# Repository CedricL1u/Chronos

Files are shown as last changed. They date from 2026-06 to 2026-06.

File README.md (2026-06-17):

# **Chronos \- A Mechanical Pomodoro Timer and Clock**

Final clock render

[Onshape CAD Link](https://cad.onshape.com/documents/4e46eab36ada7087591254e1/w/535417db20a99f0700b6b619/e/2bade0778d34ed4b7359ccd4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)

Zine

# **Overview**

Chronos is a 7-Segment mechanical display that is supposed to function as a pomodoro timer,  clock, or as a regular timer. It’s equipped with speakers that play an alarm noise when time is up and also random sound effects throughout the timer. The speakers let the user know how many pomodoro cycles they have completed after each cycle. They also help Chronos function as an alarm clock when it is put into clock mode. On the top there are two buttons and a rotary encoder which serve as inputs to control it. Chronos is powered by a ESP32-C3 on a custom PCB that drives all the electronics. This device is named Chronos because in Greek it means the quantitative measurement of time that ticks away on a clock.

# **Why does this exist?**

Chronos was mainly built to function as a pomodoro timer, but since it has four numerical displays I decided to make it usable as a clock and regular timer as well. In case you don’t know what a Pomodoro timer is, it’s a simple timer that is used with the Pomodoro Technique. The Pomodoro Technique is a study strategy where you work in short focused intervals (usually 25 minutes) followed by brief breaks (about 5 minutes). You repeat this cycle four times and then you take a longer 15-30 minute break. It’s meant to help you stay focused, reduce procrastination, and make long tasks feel more manageable by splitting them into these repeating cycles. As a student myself who struggled with procrastination and locking in during study sessions I found the pomodoro technique to be extremely useful. I mainly used online timers I found but I found them to be kind of boring so I came up with this device. It’s extremely satisfying because it makes a click every time a digit changes and it’s also cool to see as I study. It’s kind of like an ASMR sound effect while I work or study.

# **Mechanics**

The clock works through four display modules each with seven segments. Each of these 7 segments are connected to a rack and pinion which drives each segment and controls when each segment is displayed and not displayed.  

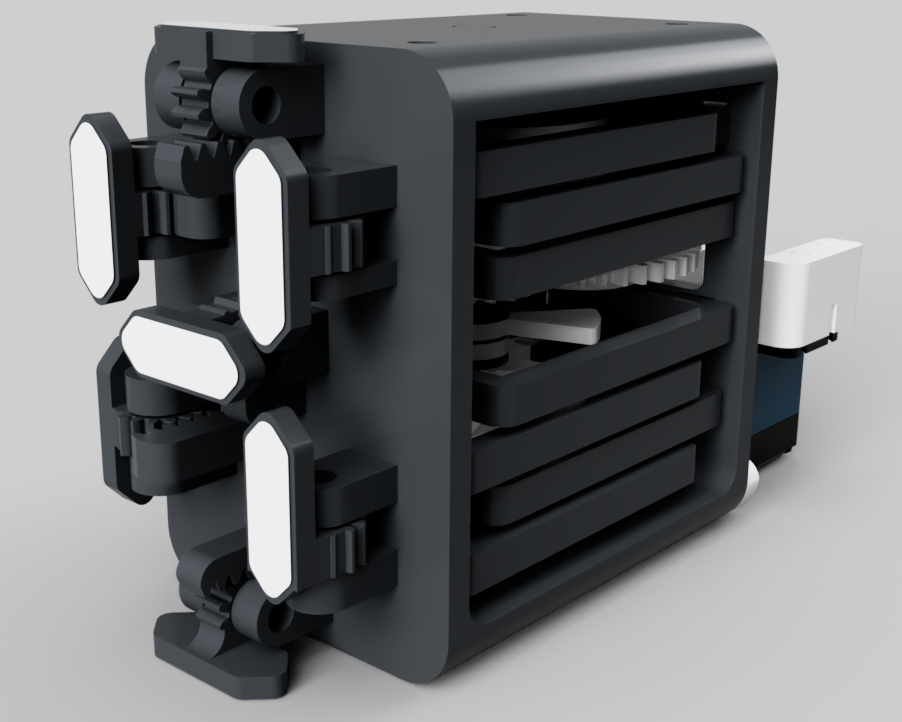
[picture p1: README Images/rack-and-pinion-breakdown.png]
Rack & Pinion Breakdown
  

Each of these racks are driven by a cam and follower mechanism that pushes each rack individually. There is a stack of 14 cams and each follower has 2 cams. One to retract it and one to extend it. Depending on the angle of the shaft different cams are extended and different cams are retracted which control the number displayed. Numbers are displayed at a 36 degree increment of the shaft. For example at 0 degrees the number 0 is displayed and at 72 degrees the number 2 is displayed.



  

The shaft is driven by a servo that is geared to it. 



# **Electronics**

This device is powered by a custom PCB I made in KiCAD that utilizes a Seed Studio XIAO ESP32-C3. On my board I have 4 servo pins which are driven by PWM signals from my microcontroller and the 5V power. There are also two MAX98357A Audio Drive ICs used to control the speakers on my device. I also have a 8-bit IO Expander IC because there weren’t enough GPIO pins on my microcontroller. The 8-Bit IO Expander communicates with my microcontroller through I2C and controls my rotary encoder switch and my two linear switches. The PCB is powered by a 8A 5V AC-DC unit that I plug into the wall and connect into my barrel jack connector. From there the power goes into a reverse polarity mosfet circuit that blocks current if the power supply is connected backwards. This P channel mosfet is then connected to my bulk 2200uF bulk capacitor that acts like a power reservoir to prevent brownouts in case the servos suddenly stall.  





# **Control**

There are 3 methods of input into the clock. A rotary encoder switch, and two cherry mx style linear mechanical keyboard switches. When you rotate the white knob in the middle you can change the duration of the timer when you are in the pomodoro or timer mode. When you click it you can pause or resume the clock. The right button lets you switch between clock mode, pomodoro mode, and timer mode. The left button lets you skip between pomodoro cycles.  


EC11EA5 Rotary Encoder Switch  


Cherry MX Style Linear Mechanical Keyboard Switch 

# **Bill of Materials**

[BOM File](https://github.com/CedricL1u/Chronos/blob/main/BOM.csv)

# **Assembly Instructions**

After you've printed all you're parts you want to first start by putting all of your fikkiwers into the front part of the casing. After you've done that you should align all of your cams on your shaft and place them all into their with your spacers. Once you've done that you need to put the cams into the followers. This can be a bit tricky, a tip I found useful was to wiggle the cams and move the followers when the cams get stuck. This can take a while but after you've done that you need to put the top plate on and screw it in, this will lock the shaft in place. After that mount the servo holder onto the back case plate and screw the servo onto the servo holder. Then screw in the servo gear and attach the back case plate into the rest of the case and align the followers such that they fit inside the hole. Repeat this 3 more times and you should have all 4 display modules. Once you have your display modules, you should first wire everything up. Wire all the jumper cables and servo wires from the pcb to their respective components. Then screw in the PCB and mount all 4 display modules, the 2 speakers, and then screw in the back plate for the case and you should be all good to go.

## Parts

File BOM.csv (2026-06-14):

Product Name | Product Description | Product Link | Unit Price | Qty | Line Total | Running Total
PJ-063BH Power Barrel Jack | Barrel Jack Connector | https://www.digikey.com/en/products/detail/same-sky-formerly-cui-devices/PJ-063BH/2161209 | $1.63000 | 1 | $1.63 | $1.63
MAX98357A | Audio Driver IC | https://www.digikey.com/en/products/detail/analog-devices-inc-maxim-integrated/MAX98357AETE-T/4936122 | $3.73000 | 2 | $7.46 | $9.09
AS03104MR-F-WP-R | Speaker | https://www.digikey.com/en/products/detail/pui-audio-inc/AS03104MR-F-WP-R/17488219 | $9.20000 | 2 | $18.40 | $27.49
Schottky Diode | Schottky Diode | https://www.digikey.com/en/products/detail/mcc-micro-commercial-components/SM5819PL-TP/1793253 | $0.21000 | 1 | $0.21 | $27.70
PCF8574ADWR I2C I/O Expander | IO Expander | https://www.digikey.com/en/products/detail/texas-instruments/PCF8574ADWR/574749 | $1.59000 | 1 | $1.59 | $29.29
10µF 25V Ceramic Cap |  | https://www.digikey.com/en/products/detail/murata-electronics/GRM188R61E106KA73D/9867922 | $0.26000 | 4 | $1.04 | $30.33
0.1µF 25V Ceramic Cap |  | https://www.digikey.com/en/products/detail/kemet/C0603C104K3RACTU/416044 | $0.10000 | 4 | $0.40 | $30.73
10nF 50V Ceramic Cap |  | https://www.digikey.com/en/products/detail/kemet/C0603C103K5RACTU/3838393 | $0.10000 | 4 | $0.40 | $31.13
2200µF 16V Electrolytic Cap | Panasonic / EEU-FR1C222 | https://www.digikey.com/en/products/detail/panasonic-electronic-components/EEU-FR1C222/2433536 | $1.67000 | 1 | $1.67 | $32.80
3-Pin Servo Header |  | https://www.digikey.com/en/products/detail/w%C3%BCrth-elektronik/61300311121/4846825 | $0.13000 | 4 | $0.52 | $33.32
13-Pin Header |  | https://www.digikey.com/en/products/detail/w%C3%BCrth-elektronik/61301311121/4846847 | $0.75000 | 1 | $0.75 | $34.07
AOD403 P-Channel MOSFET | For reverse polarity circuit | https://www.digikey.com/en/products/detail/alpha-omega-semiconductor-inc/AOD403/1855873 | $2.05000 | 1 | $2.05 | $36.12
10kΩ Resistor 0603 (R1, R3–R12) |  | https://www.digikey.com/en/products/detail/yageo/RC0603FR-0710KL/726880 | $0.02500 | 15 | $0.38 | $36.50
210kΩ Resistor 0603 (R2) |  | https://www.digikey.com/en/products/detail/yageo/RC0603FR-07210KL/727052 | $0.10000 | 2 | $0.20 | $36.70
DigiKey Shipping |  |  | $8.49 | 1 | $8.49 | $45.19
DigiKey Tariff |  |  | $8.32 | 1 | $8.32 | $53.51
DigiKey Sales Tax |  |  | $4.61 | 1 | $4.61 | $58.12
MG995 Metal Gear Servo 4-Pack |  | https://www.amazon.com/dp/B07NQJ1VZ2 | $19.82000 | 1 | $19.82 | $77.94
ALITOVE 5V 8A 40W Power Supply |  | https://www.amazon.com/dp/B078RZBL8X | $20.39000 | 1 | $20.39 | $98.33
PCBS |  | https://jlcpcb.com | $0.64000 | 5 | $3.20 | $101.53
Solder Paste Stencil |  | https://jlcpcb.com | $7.11000 | 1 | $7.11 | $108.64
JLCPCB Shipping (net of discount) |  |  | $28.23 | 1 | $28.23 | $136.87
JLCPCB Taxes |  |  | $0.84 | 1 | $0.84 | $137.71
XIAO ESP32-C3 |  | https://www.seeedstudio.com/Seeed-XIAO-ESP32C3-p-5431.html | $10.69 | 1 | $10.69 | $148.40

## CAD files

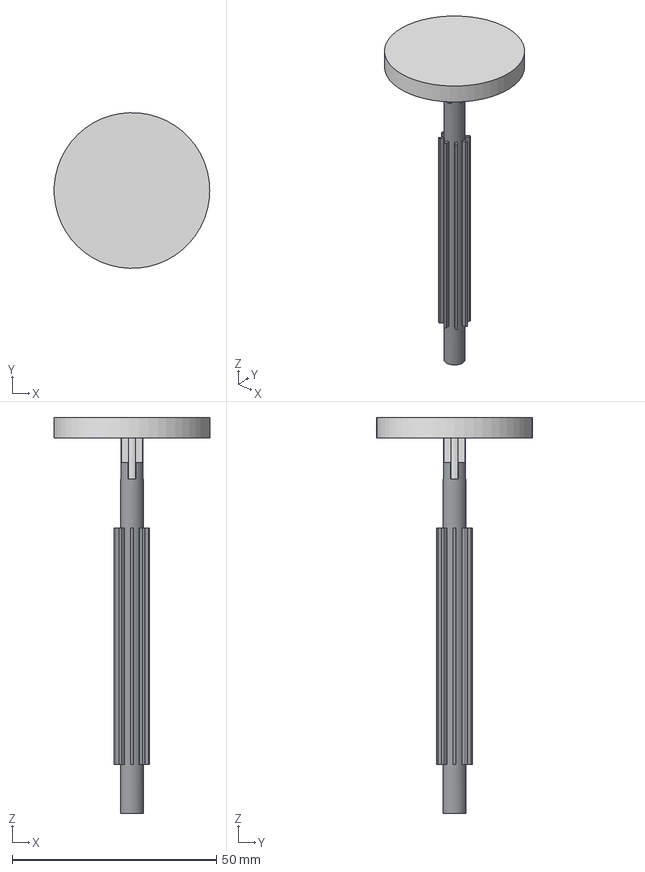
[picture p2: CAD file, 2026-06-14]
CAD Files/Axle.step
38.1 x 38.1 x 96.9 mm

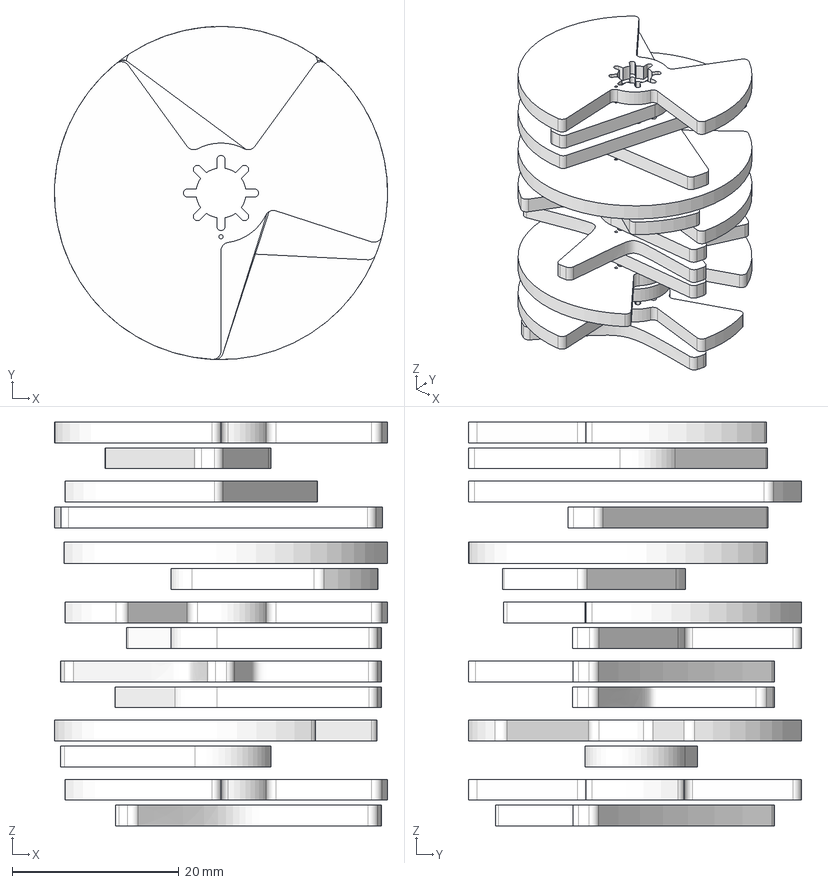
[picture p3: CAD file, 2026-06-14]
CAD Files/Cams.step
40.0 x 40.0 x 48.5 mm

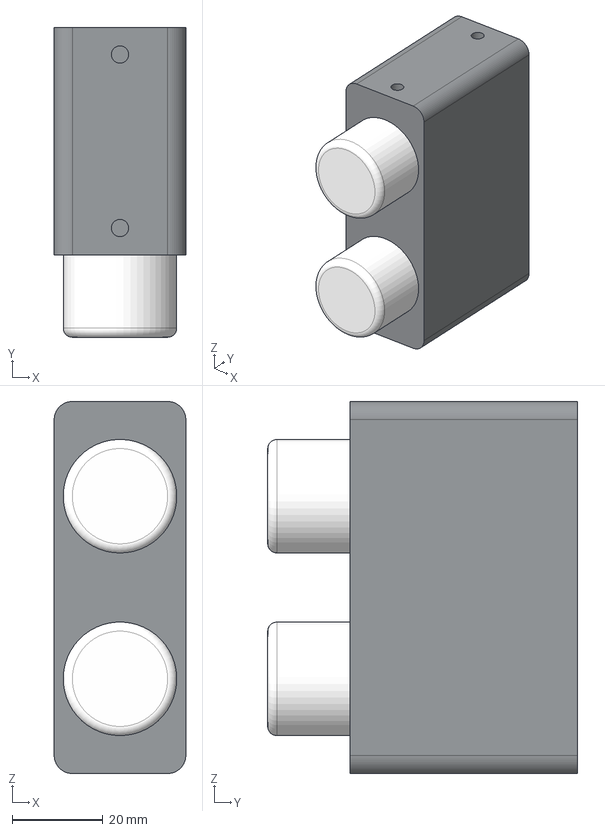
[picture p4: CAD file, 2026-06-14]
CAD Files/Colon.step
29.0 x 68.2 x 81.9 mm

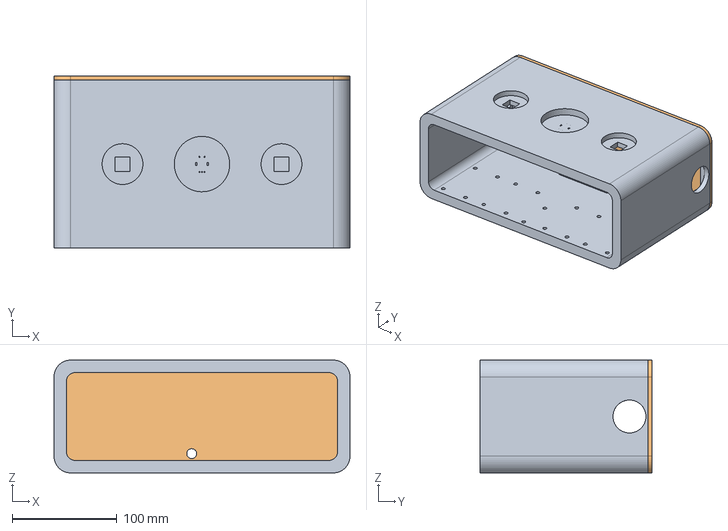
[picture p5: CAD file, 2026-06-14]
CAD Files/Clock Case.step
283.0 x 164.4 x 107.9 mm

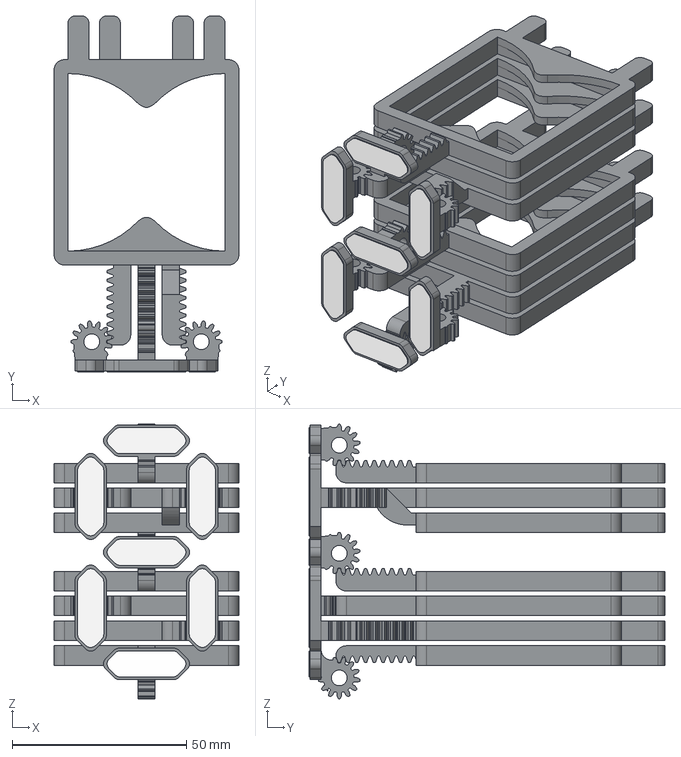
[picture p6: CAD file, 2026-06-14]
CAD Files/Display Module.step
53.0 x 102.1 x 78.7 mm

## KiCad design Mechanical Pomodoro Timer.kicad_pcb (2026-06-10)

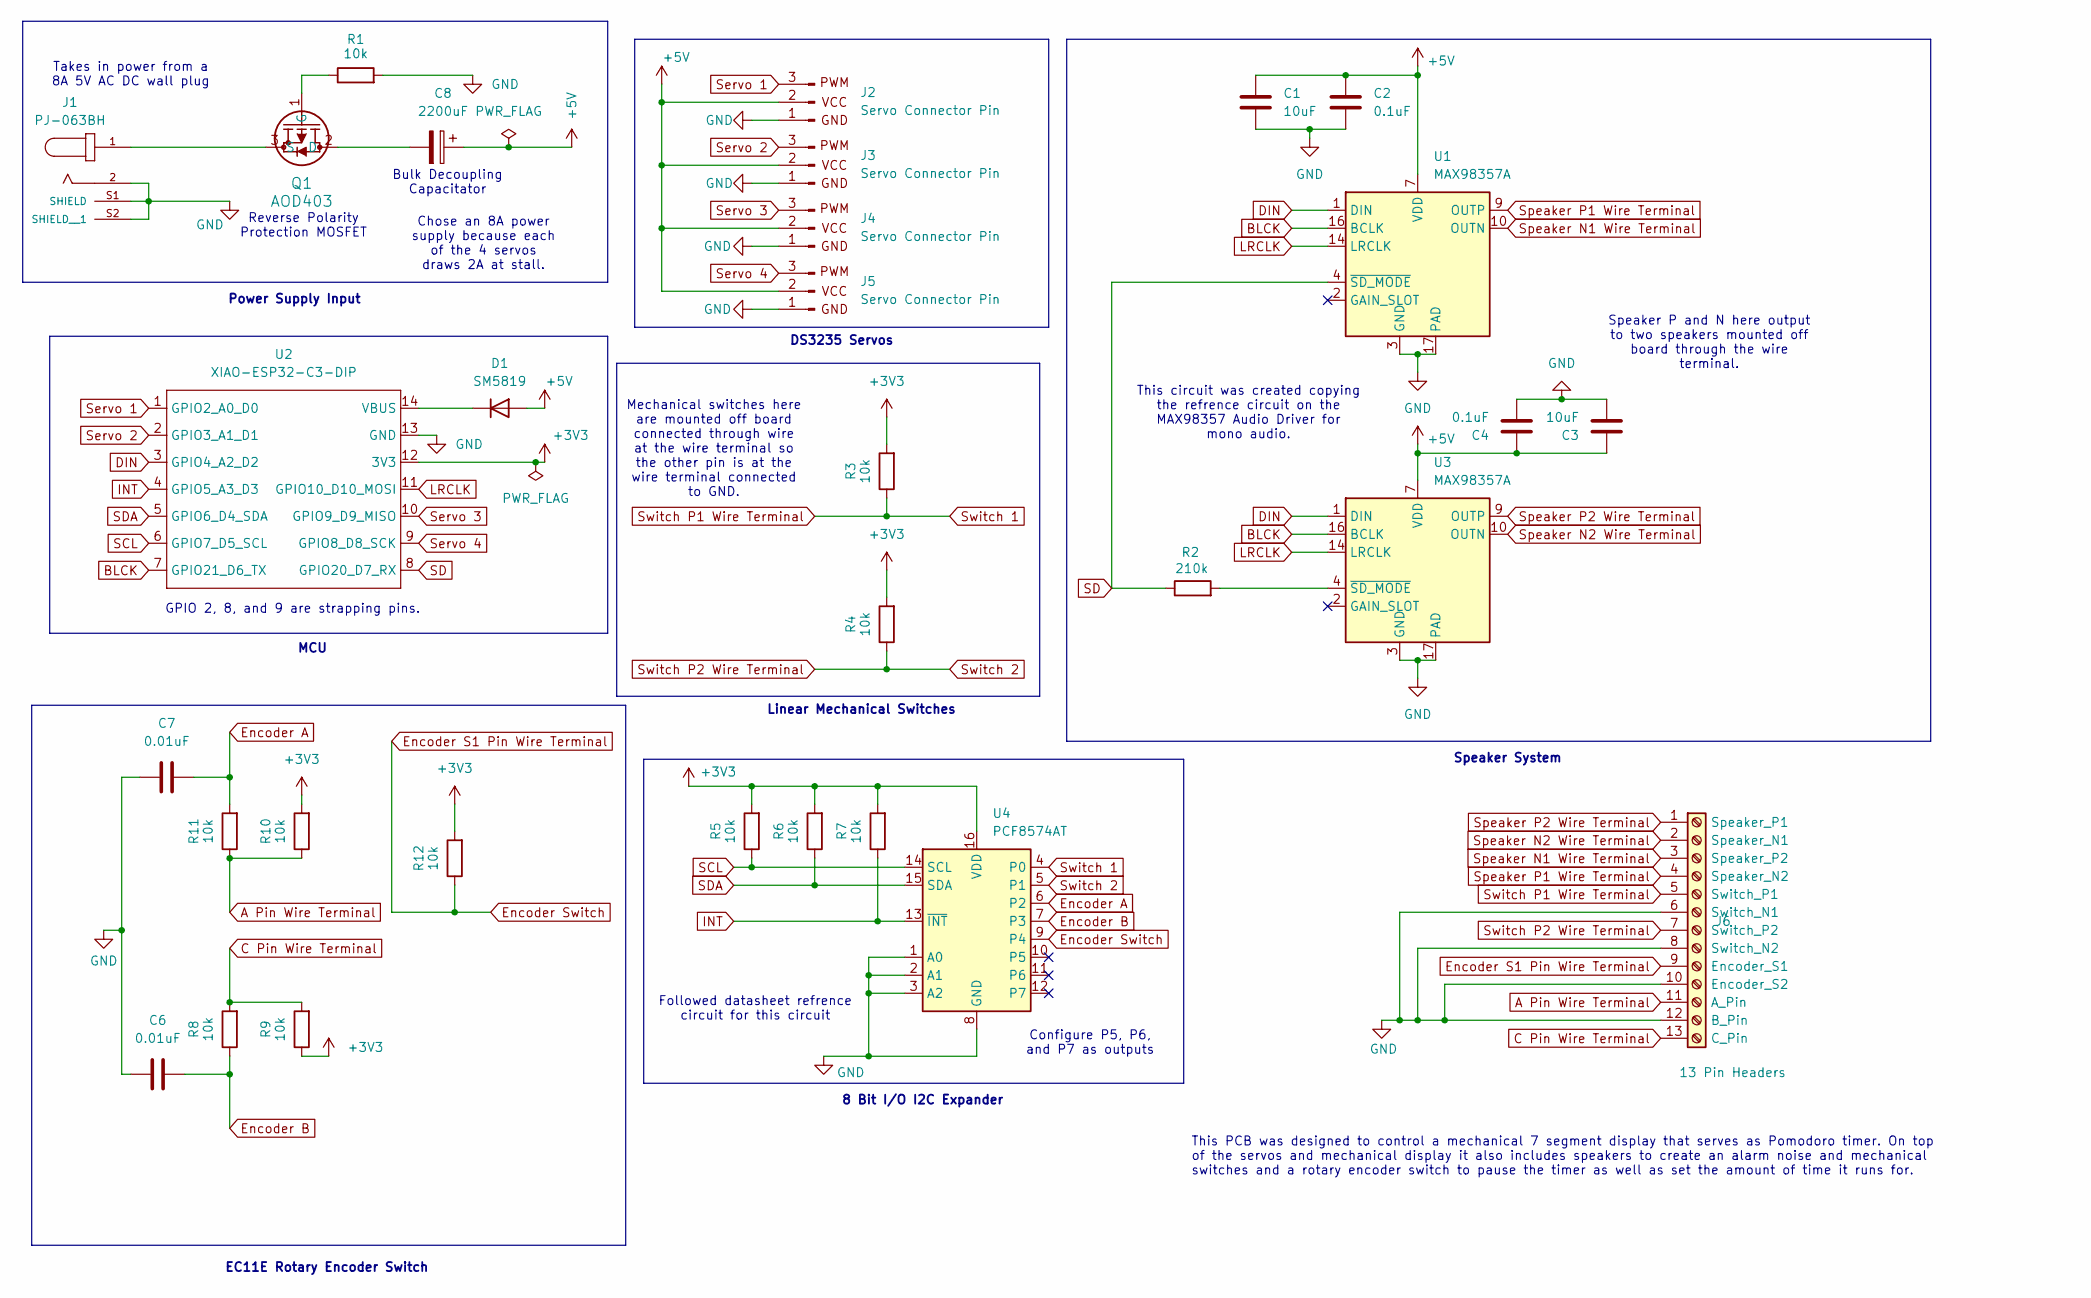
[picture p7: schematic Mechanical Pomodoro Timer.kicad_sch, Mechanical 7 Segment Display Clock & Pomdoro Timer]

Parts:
C1, C3: 10uF; C_0603_1608Metric_Pad1.08x0.95mm_HandSolder
C2, C4: 0.1uF; C_0603_1608Metric_Pad1.08x0.95mm_HandSolder
C6, C7: 0.01uF; C_0603_1608Metric_Pad1.08x0.95mm_HandSolder
C8: 2200uF; CAPPRD500W60D1250H2000
D1: SM5819; D_SOD-123F
J1: PJ-063BH; CUI_PJ-063BH; PARTREV 1.02
J2, J3, J4, J5: Servo Connector Pin; PinHeader_1x03_P2.54mm_Vertical
J6: 13 Pin Headers; PinHeader_1x13_P2.54mm_Vertical
Q1: AOD403; TO-252-3_TabPin2
R1, R3, R4, R5, R6, R7, R8, R9, R10, R11, R12: 10k; R_0603_1608Metric_Pad0.98x0.95mm_HandSolder
R2: 210k; R_0603_1608Metric_Pad0.98x0.95mm_HandSolder
U1, U3: MAX98357A; TQFN-16-1EP_3x3mm_P0.5mm_EP1.23x1.23mm
U2: XIAO-ESP32-C3-DIP; XIAO-ESP32-C3-SMD
U4: PCF8574AT; SOIC-16W_7.5x10.3mm_P1.27mm

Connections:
+3V3: R3.2, R4.2, R5.2, R6.2, R7.2, R9.1, R10.2, R12.2, U2.12 (3V3), U4.16 (VDD)
+5V: C1.1, C2.1, C3.1, C4.1, C8.P, D1.2 (A), J2.2, J3.2, J4.2, J5.2, U1.7 (VDD), U1.8 (VDD), U3.7 (VDD), U3.8 (VDD)
A Pin Wire Terminal: J6.11 (A_Pin), R10.1, R11.1
BLCK: U1.16 (BCLK), U2.7 (GPIO21_D6_TX), U3.16 (BCLK)
C Pin Wire Terminal: J6.13 (C_Pin), R8.2, R9.2
DIN: U1.1 (DIN), U2.3 (GPIO4_A2_D2), U3.1 (DIN)
Encoder A: C7.2, R11.2, U4.6 (P2)
Encoder B: C6.2, R8.1, U4.7 (P3)
Encoder S1 Pin Wire Terminal: J6.9 (Encoder_S1), R12.1, U4.9 (P4)
GND: C1.2, C2.2, C3.2, C4.2, C6.1, C7.1, J1.2, J1.S1 (SHIELD), J1.S2 (SHIELD__1), J2.1, J3.1, J4.1, J5.1, J6.6 (Switch_N1), J6.8 (Switch_N2), J6.10 (Encoder_S2), J6.12 (B_Pin), R1.2, U1.3 (GND), U1.11 (GND), U1.15 (GND), U1.17 (PAD), U2.13 (GND), U3.3 (GND), U3.11 (GND), U3.15 (GND), U3.17 (PAD), U4.1 (A0), U4.2 (A1), U4.3 (A2), U4.8 (GND)
INT: R7.1, U2.4 (GPIO5_A3_D3), U4.13 (~INT)
LRCLK: U1.14 (LRCLK), U2.11 (GPIO10_D10_MOSI), U3.14 (LRCLK)
unnamed: D1.1 (K), U2.14 (VBUS)
unnamed: C8.N, Q1.2 (D)
unnamed: Q1.1 (G), R1.1
unnamed: J1.1, Q1.3 (S)
unnamed: R2.2, U3.4 (~SD_MODE)
SCL: R5.1, U2.6 (GPIO7_D5_SCL), U4.14 (SCL)
SD: R2.1, U1.4 (~SD_MODE), U2.8 (GPIO20_D7_RX)
SDA: R6.1, U2.5 (GPIO6_D4_SDA), U4.15 (SDA)
Servo 1: J2.3, U2.1 (GPIO2_A0_D0)
Servo 2: J3.3, U2.2 (GPIO3_A1_D1)
Servo 3: J4.3, U2.10 (GPIO9_D9_MISO)
Servo 4: J5.3, U2.9 (GPIO8_D8_SCK)
Speaker N1 Wire Terminal: J6.3 (Speaker_P2), U1.10 (OUTN)
Speaker N2 Wire Terminal: J6.2 (Speaker_N1), U3.10 (OUTN)
Speaker P1 Wire Terminal: J6.4 (Speaker_N2), U1.9 (OUTP)
Speaker P2 Wire Terminal: J6.1 (Speaker_P1), U3.9 (OUTP)
Switch 1: J6.5 (Switch_P1), R3.1, U4.4 (P0)
Switch 2: J6.7 (Switch_P2), R4.1, U4.5 (P1)

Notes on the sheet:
This PCB was designed to control a mechanical 7 segment display that serves as Pomodoro timer. On top of the servos and mechanical display it also includes speakers to create an alarm noise and mechanical switches and a rotary encoder switch to pause the timer as well as set the amount of time it r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
This circuit was created copying the refrence circuit on the MAX98357 Audio Driver for mono audio.
DS3235 Servos
Linear Mechanical Switches
MCU
8 Bit I/O I2C Expander
Power Supply Input
Reverse Polarity Protection MOSFET
Speaker P and N here output to two speakers mounted off board through the wire terminal.
Takes in power from a 8A 5V AC DC wall plug
Bulk Decoupling Capacitator
Followed datasheet refrence circuit for this circuit
GPIO 2, 8, and 9 are strapping pins.
Chose an 8A power supply because each of the 4 servos draws 2A at stall.
EC11E Rotary Encoder Switch
Mechanical switches here are mounted off board connected through wire at the wire terminal so the other pin is at the wire terminal connected to GND.
Configure P5, P6, and P7 as outputs
Speaker System

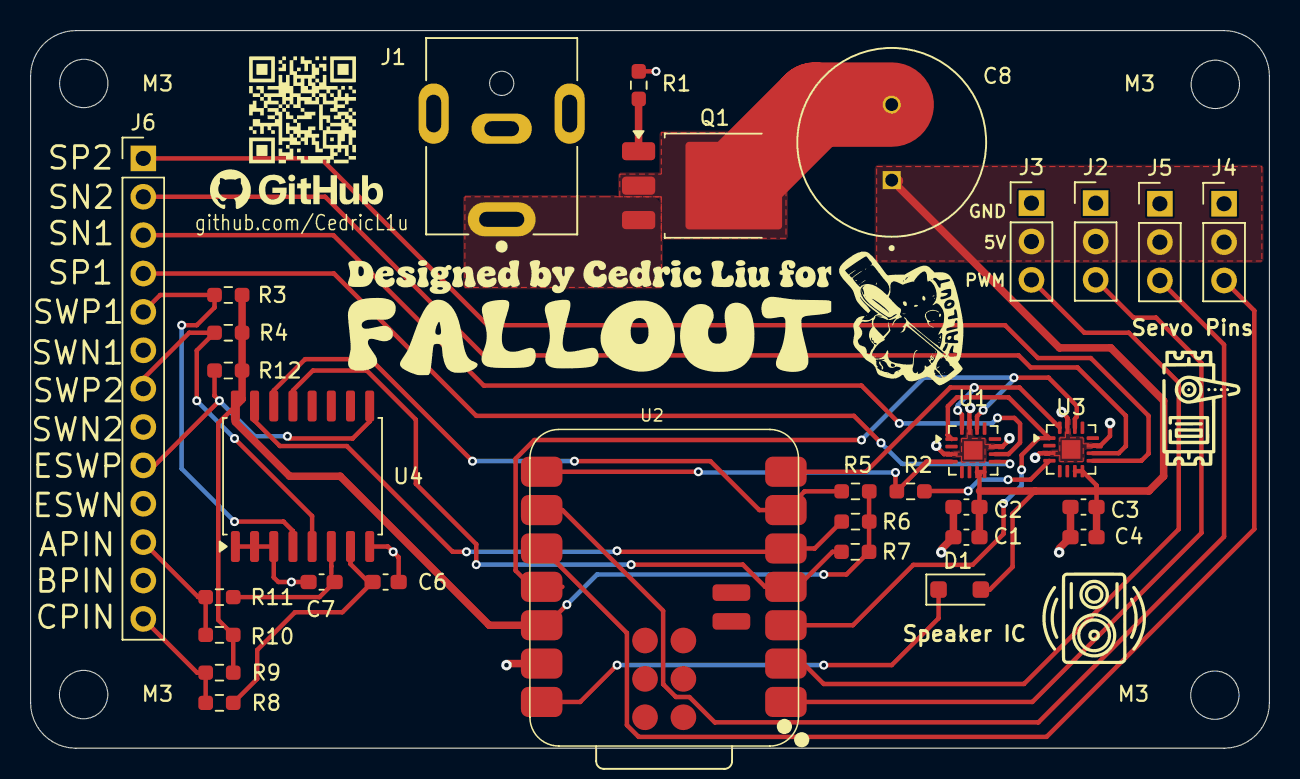
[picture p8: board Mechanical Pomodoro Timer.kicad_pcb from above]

Board: 2 copper layers, 82.0 x 47.5 mm, 36 parts (0 on the bottom side), 30 nets.

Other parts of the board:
M3, M3#2, M3#3, M3#4: MountingHole_3.2mm_M3
Speakers: LOGO

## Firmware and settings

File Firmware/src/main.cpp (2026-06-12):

#include <Arduino.h>
#include <IoAbstraction.h>   // for taskManager
#include "modes.h"

// The single source of truth for the active mode (declared extern in modes.h).
Mode currentMode = MODE_POMODORO;

// Switches mode and runs the new mode's "enter" hook so it can draw itself.
void changeMode(Mode newMode) {
    currentMode = newMode;
    switch (currentMode) {
        case MODE_POMODORO: pomodoroEnter(); break;
        case MODE_CLOCK:    clockEnter();    break;
        case MODE_TIMER:    timerEnter();    break;
    }
}

void setup() {
    Serial.begin(115200);

    displaySetup();
    inputSetup();
    audioSetup();

    pomodoroSetup();
    clockSetup();
    timerSetup();

    // Start in the default mode and draw it.
    changeMode(MODE_POMODORO);
}

void loop() {
    // IoAbstraction: services switches/encoder interrupts and callbacks.
    taskManager.runLoop();

    // Keep the audio library streaming (no-op when nothing is playing).
    audioLoop();

    // Run only the active mode's per-frame logic.
    switch (currentMode) {
        case MODE_POMODORO: pomodoroLoop(); break;
        case MODE_CLOCK:    clockLoop();    break;
        case MODE_TIMER:    timerLoop();    break;
    }
}

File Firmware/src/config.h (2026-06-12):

#pragma once

// I2C
#define I2C_SDA_Pin D4
#define I2C_SCL_Pin D5
#define I2C_INT_Pin D3
#define PCF8574_ADDRESS 0x38

//Servos
#define Servo1_Pin D0
#define Servo2_Pin D1
#define Servo3_Pin D9
#define Servo4_Pin D8

//Switches
#define Switch1_Pin 0
#define Switch2_Pin 1
#define Encoder_Switch 4

//Rotary Encoder
#define Encoder_A 2
#define Encoder_B 3

//Speakers
#define I2S_BCLK_Pin D6
#define I2S_DOUT_Pin D3
#define I2S_LRCLK_Pin D2

//WiFi + time (clock mode)
#define WIFI_SSID     "YOUR_WIFI_NAME"
#define WIFI_PASSWORD "YOUR_WIFI_PASSWORD"
// NTP / timezone. GMT offset in seconds (e.g. EST = -5*3600), DST offset in seconds.
#define NTP_SERVER       "pool.ntp.org"
#define GMT_OFFSET_SEC   (-5 * 3600)
#define DST_OFFSET_SEC   (3600)
